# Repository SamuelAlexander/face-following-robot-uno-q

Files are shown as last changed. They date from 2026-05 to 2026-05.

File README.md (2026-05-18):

# Face-following robot with Arduino UNO Q and Edge Impulse

Build a desk-sized robot that detects a human face using on-device ML and steers toward it in real time,  all running on the [Arduino UNO Q](https://store.arduino.cc/products/uno-q).

**Created by:** Samuel Alexander  
**Edge Impulse public project:** https://studio.edgeimpulse.com/public/953867/live  
**GitHub repository:** https://github.com/SamuelAlexander/face-following-robot-uno-q  
**Demonstration video:** https://youtu.be/TYtrBvlE7Mc

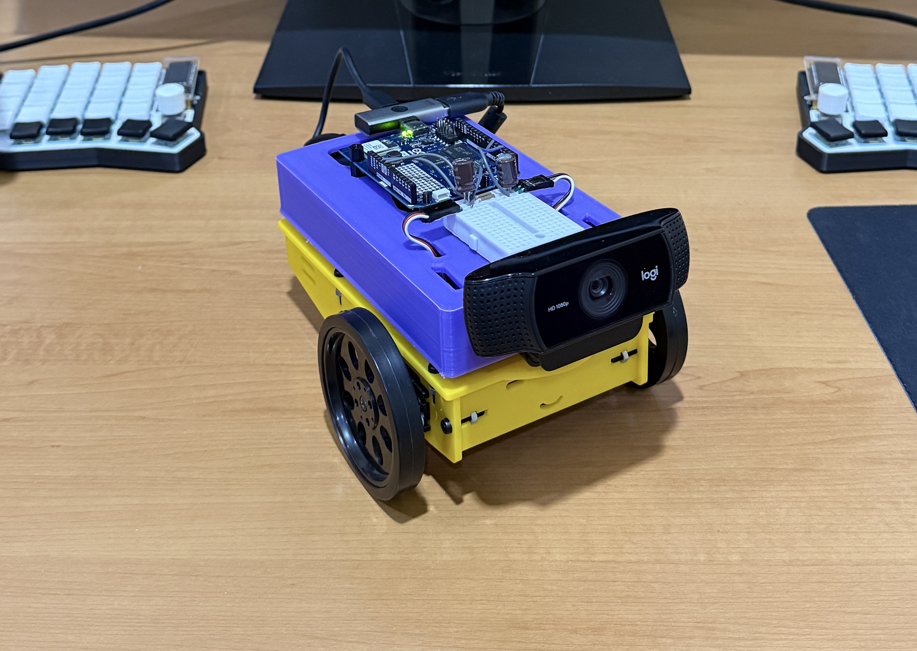
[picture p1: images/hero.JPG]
hero


## Introduction

This project combines computer vision and robotics on a single board. A camera captures video, a lightweight face-detection model (powered by Edge Impulse) locates the face, and a proportional controller converts that position into differential wheel commands, all at ~10-15 FPS.

The UNO Q's **split architecture** makes this possible:

- **MPU** (Qualcomm, Linux) --> runs the ML model and control logic in Python
- **MCU** (STM32, Zephyr RTOS) --> drives servo PWM with real-time precision

The two processors communicate over **Bridge RPC**, a MessagePack-based protocol over an internal serial link. This separation keeps heavy inference off the real-time path and motor control deterministic.

A browser-based **Web UI** lets you monitor detections and tune steering parameters live, no recompilation needed.

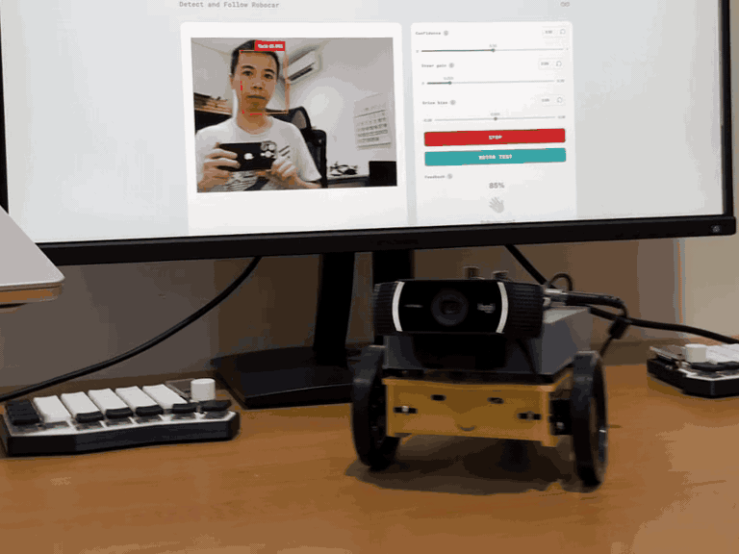
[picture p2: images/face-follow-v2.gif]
face-follow


### What you'll learn

- How the UNO Q's MPU/MCU split architecture works
- Using App Lab **bricks** (pre-built middleware) for AI and web interfaces
- Bridge RPC communication between Python and an Arduino sketch
- Proportional steering control for differential-drive robots
- Live parameter tuning through a Socket.IO web dashboard

## Prerequisites

### Hardware

| Component | Used in This Project | Notes |
|---|---|---|
| Arduino UNO Q | — | 2 GB or 4 GB variant |
| USB webcam | Logitech C922 Pro Stream | Most UVC-compatible webcams work |
| 2x continuous-rotation servo | Parallax Continuous Rotation Servo | Any continuous servo with 1000-2000 us pulse range |
| USB-C power bank (PD) | 20000 mAh, USB-C PD output | Must supply stable 5 V / 2+ A |
| USB-C splitter | With USB-A port | Powers UNO Q via USB-C, camera via USB-A |
| Small decoupling capacitors | 100 uF electrolytic across servo power/GND | Reduces servo electrical noise |
| Robot chassis | Custom 3D-printed (STL files included) | Any two-wheel platform works |
| Jumper wires | — | Signal + power for servos |

### Software

- **Arduino App Lab v0.6** or later (runs in-browser, no local install needed)
- A computer on the same network as the UNO Q
- Edge Impulse Studio account

### Source code

The full project source is available at: https://github.com/SamuelAlexander/face-following-robot-uno-q  

## Architecture overview

The system has three layers:

```
┌──────────────┐    Socket.IO   ┌────────────────────────────────┐
│   Browser    │◄──────────────►│  MPU (Linux / Python)          │
│   Web UI     │                │  - VideoObjectDetection brick  │
│   Tuning +   │                │  - Steering controller         │
│   Monitoring │                │  - WebUI brick                 │
└──────────────┘                └──────────┬─────────────────────┘
                                           │ Bridge RPC (MsgPack)
                                ┌──────────▼─────────────────────┐
                                │  MCU (STM32 / Zephyr RTOS)     │
                                │  - Receives pulse commands     │
                                │  - Drives PWM on D3 + D6       │
                                └──────────┬─────────────────────┘
                                           │ PWM (50 Hz, 1000-2000 us)
                                ┌──────────▼─────────────────────┐
                                │  Left servo    Right servo     │
                                └────────────────────────────────┘
```

**Why split MPU and MCU?** ML inference is computationally heavy and non-deterministic, it belongs on a Linux processor. Servo PWM timing is safety-critical and must be jitter-free, it belongs on a real-time microcontroller. Bridge RPC connects the two with ~8 ms round-trip latency.

## Hardware assembly

### Chassis overview

The robot uses a simple **differential-drive** layout:

- Two continuous-rotation servos mounted on opposite sides
- A rear caster or skid point for stability
- A top-mounted platform for the UNO Q and camera
- The USB power bank sits on or below the platform as ballast

Continuous-rotation servos simplify wiring. A 1500 us pulse means stop, below 1500 spins one way, above 1500 spins the other.

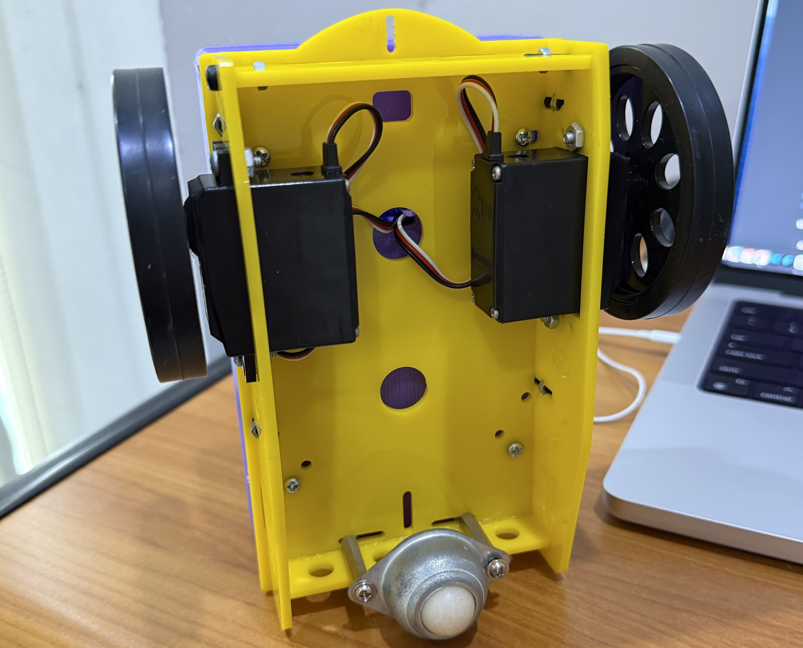
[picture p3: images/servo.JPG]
servo


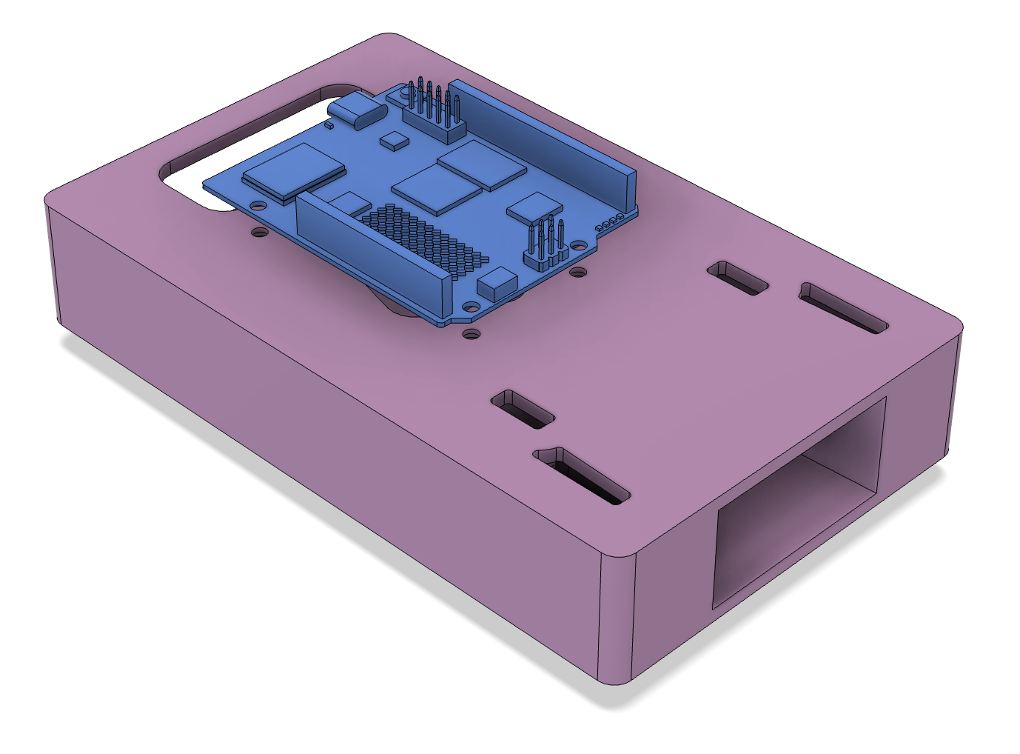
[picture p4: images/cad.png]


### Wiring

| Servo | Signal Pin | Power | Ground |
|---|---|---|---|
| Left wheel | D3 | 5 V | GND |
| Right wheel | D6 | 5 V | GND |

Place a **100 uF capacitor** across the servo power and ground rails to absorb current spikes.

Connect the webcam to the USB-A port on the USB-C splitter. The USB-C side powers the UNO Q.

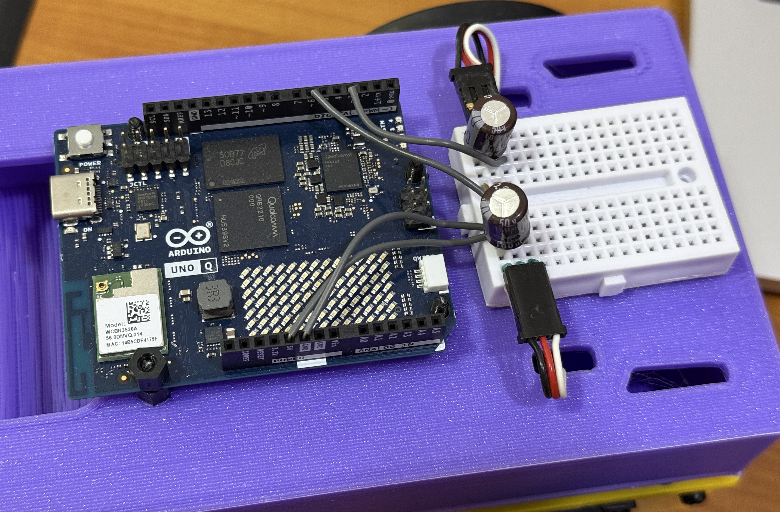
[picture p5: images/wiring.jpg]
wiring


> **Note:** The right servo is mounted mirrored relative to the left. The firmware handles this with a pulse inversion flag, no crossed wires needed.

## Project setup in App Lab

### File structure

Every App Lab project follows this layout:

```
detect-and-follow-robocar/
├── app.yaml              # App manifest: bricks and model selection
├── python/
│   └── main.py           # MPU application (detection + control)
├── sketch/
│   ├── sketch.ino        # MCU firmware (servo PWM)
│   └── sketch.yaml       # Build config (board, libraries)
└── assets/
    ├── index.html         # Web UI page
    ├── app.js             # Web UI logic (Socket.IO client)
    └── style.css          # Styling
```

### Configuring bricks

**Bricks** are pre-built middleware packages that run on the MPU. They provide high-level capabilities without writing boilerplate. This project uses two:

In `app.yaml`:

```yaml
name: Detect and follow robocar
description: Robot car that follows a target object.
bricks:
- arduino:video_object_detection:
    model: face-detection
- arduino:web_ui: {}
icon: 🚙
```

- **`video_object_detection`**, captures camera frames, runs the face-detection model, and delivers results to your Python code via callbacks
- **`web_ui`**, serves the HTML/JS dashboard and provides a Socket.IO server for real-time communication

The `model: face-detection` line selects a built-in lightweight face-detection model. No training or Edge Impulse account needed.

### Sketch dependencies

In `sketch/sketch.yaml`, the key libraries are **Arduino_RouterBridge** (Bridge RPC) and **Servo** (PWM output):

```yaml
profiles:
  default:
    fqbn: arduino:zephyr:unoq
    platforms:
      - platform: arduino:zephyr
    libraries:
      - Arduino_RouterBridge (0.4.1)
      - Servo
      - MsgPack (0.4.2)
```

## The MCU sketch: Servo control

The MCU firmware is intentionally minimal, it receives pulse-width commands over Bridge RPC and writes them to the PWM hardware. All decision-making lives on the MPU.

### Bridge RPC endpoint

The sketch exposes a single function that the MPU can call. It uses the Arduino **Servo** library for reliable pin-level PWM output:

```cpp
#include <Arduino_RouterBridge.h>
#include <Servo.h>

Servo leftServo;
Servo rightServo;

bool set_wheel_pwm(int left_us, int right_us) {
  uint32_t left  = clamp_pulse_us(left_us);   // Clamp to 1000-2000
  uint32_t right = clamp_pulse_us(right_us);

  left  = apply_invert(left,  kInvertLeftWheel);   // false
  right = apply_invert(right, kInvertRightWheel);   // true — right is mirrored

  leftServo.writeMicroseconds(left);    // D3
  rightServo.writeMicroseconds(right);  // D6
  return true;
}

void setup() {
  Bridge.begin();
  leftServo.attach(3);
  rightServo.attach(6);
  leftServo.writeMicroseconds(1500);   // Start stopped
  rightServo.writeMicroseconds(1500);
  Bridge.provide_safe("set_wheel_pwm", set_wheel_pwm);
}

void loop() {}   // All control is event-driven via RPC
```

**Key concepts:**

- **Arduino Servo library** handles PWM output via `attach(pin)` and `writeMicroseconds()`. This is more portable than the low-level Zephyr PWM API (`pwm_set_dt`), which depends on devicetree index mappings that can vary between board revisions.
- **`Bridge.provide_safe()`** registers the function so it runs in the Arduino `loop()` context, safe for hardware operations like PWM writes. Never use `Bridge.provide()` for GPIO/servo/motor calls, as that runs in a background RPC thread where hardware APIs can fail.
- **Pulse inversion** handles the mirrored right servo: `inverted = 3000 - pulse`. This mirrors the pulse around the 1500 us stop point, so the same "forward" command from Python moves both wheels in the same physical direction.
- **Empty `loop()`** is correct, the Bridge library hooks into the loop internally to dispatch queued `provide_safe` callbacks.

### Continuous-rotation servo basics

| Pulse (us) | Behavior |
|---|---|
| 1500 | Stop |
| 1000 | Full speed, one direction |
| 2000 | Full speed, opposite direction |

The closer to 1500, the slower the wheel turns. This project uses offsets up to ±125 us for responsive but desk-safe motion.

## The MPU application: Detection to steering

The Python application on the MPU handles three responsibilities: receiving detections from the vision brick, computing steering commands, and communicating with both the MCU and the web UI.

### Brick initialization

```python
from arduino.app_utils import App, Bridge
from arduino.app_bricks.web_ui import WebUI
from arduino.app_bricks.video_objectdetection import VideoObjectDetection

ui = WebUI()
detection_stream = VideoObjectDetection(confidence=0.5, debounce_sec=0.0)
```

The `VideoObjectDetection` brick fires a callback every time it processes a frame. The `on_detect_all` variant fires for every frame, including ones with no detections, useful for keeping a watchdog timestamp fresh:

```python
detection_stream.on_detect_all(on_detections)
App.run()
```

### Detection format

The brick delivers detections as a dictionary, with each label mapped to a **list** of detection instances:

```python
{
    "face": [
        {"confidence": 0.89, "bounding_box_xyxy": (144, 83, 234, 209)},
        # ...more faces if multiple detected
    ]
}
```

Each instance contains a `confidence` score and a `bounding_box_xyxy` tuple of `(x_min, y_min, x_max, y_max)` in pixel coordinates. The `TARGET_CLASS` constant must match the model's label exactly, "face"` for the built-in face-detection model.

> **Important:** The per-label value is always a list, even for a single detection. Code that expects a plain dict per label (without the list wrapper) will silently miss all detections.

### Proportional steering controller

The controller converts the face's horizontal position into differential wheel commands:

```
1. Find the face's bounding box center
2. Normalize to 0.0 (left edge) — 1.0 (right edge)
3. Compute heading error: (center - 0.5) x 2.0  →  range -1.0 to +1.0
4. Apply deadband (ignore small errors to suppress jitter)
5. Shape response with a power curve (compress large errors)
6. Scale by STEER_GAIN → turn speed
7. Convert to differential pulses: left = 1500 + turn, right = 1500 - turn
```

```python
heading_error = (target_cx - 0.5) * 2.0
if abs(heading_error) < CENTER_DEADBAND:
    heading_error = 0.0

shaped = math.copysign(abs(heading_error) ** STEER_CURVE, heading_error)
turn = clamp(STEER_SIGN * STEER_GAIN * shaped, -MAX_TURN_SPEED, MAX_TURN_SPEED)

left_us  = speed_to_pulse(turn)    # 1500 + turn x 500
right_us = speed_to_pulse(-turn)   # 1500 - turn x 500
```

The **power curve** (`STEER_CURVE = 0.4`) makes the response more aggressive for small errors and softer near the frame edges, a simple alternative to PID that works well for this use case.

### Coasting and lost target

When the face momentarily disappears (occlusion, blink, brief look-away), the controller **coasts** on the last-known position for `TRACKING_TIMEOUT` seconds (default 0.5s) before declaring the target lost. This avoids jittery stop-start behavior.

When the target is truly lost, the robot stops. An optional search mode (disabled by default) slowly rotates to scan for the face.

### Bridge communication and rate limiting

The UNO Q Bridge has no internal queue, sending commands too fast crashes the serial link. The application rate-limits Bridge calls to a maximum of 20 Hz (50 ms intervals):

```python
MIN_BRIDGE_INTERVAL = 0.05  # seconds

if now - _last_bridge_ts < MIN_BRIDGE_INTERVAL:
    return   # Skip this update

Bridge.notify("set_wheel_pwm", left_us, right_us)
```

`Bridge.notify()` is fire-and-forget (no response waited), which avoids blocking the inference loop. `Bridge.call()` would wait for a return value and slow down the control loop.

> **Safety note:** The emergency stop bypasses rate limiting entirely to guarantee the MCU receives the stop command immediately.

### Watchdog

A background thread checks whether detection callbacks have stopped arriving. If no callback fires for 1.5 seconds (indicating a camera or pipeline failure), the watchdog forces a stop command:

```python
def _watchdog_loop():
    while True:
        time.sleep(0.25)
        if time.monotonic() - _last_detection_ts > NO_DETECTION_TIMEOUT:
            send_lost_target_command()
```

## The web UI

The dashboard runs in any browser on the same network and provides live monitoring and parameter tuning.

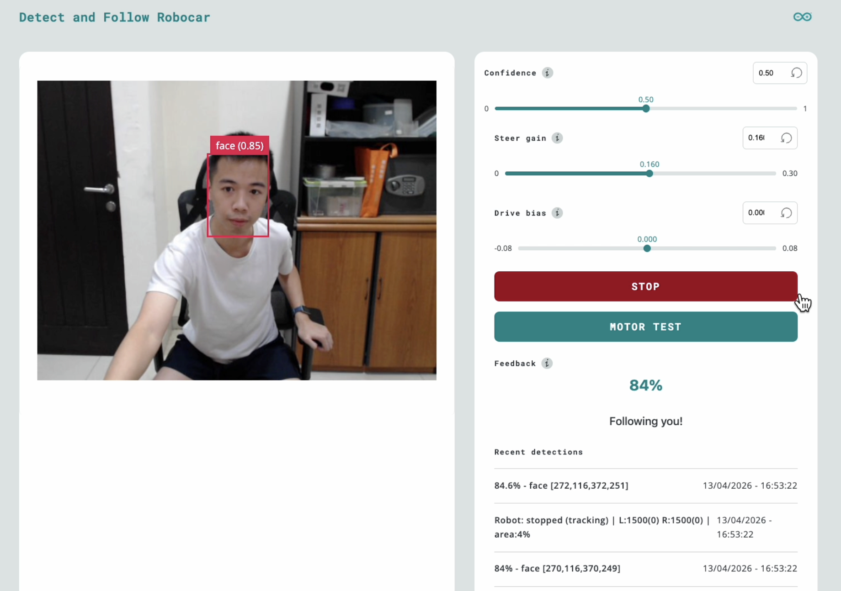
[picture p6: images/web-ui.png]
web-ui


### Features

| Element | Function |
|---|---|
| **Video stream** | Live camera feed via iframe (port 4912) |
| **Confidence slider** | Adjusts minimum detection confidence (0.0-1.0) |
| **Steer gain slider** | Controls how aggressively the robot turns (0-0.30) |
| **Drive bias slider** | Adds fixed forward/backward offset (-0.08 to +0.08) |
| **Emergency stop** | Immediately halts all wheel motion |
| **Motor test** | Runs a left-right-stop sequence to verify servo wiring |
| **Feedback** | Visual confirmation when a face is detected |
| **Recent detections** | Live log of the last 5 detection and state events |

All slider changes take effect immediately via Socket.IO, no restart required. This makes tuning fast: adjust a slider, observe the robot's response, repeat.

## Deploy and run

### App Lab GUI

1. Open **Arduino App Lab** in your browser
2. Create a new app or import the project files
3. Click **Run**, App Lab compiles the sketch, flashes the MCU, and starts the Python app

### First boot checklist

1. **Check the log** for the `sample_detections` line, it prints the raw detection payload on the first frame. Verify:
   - The label is `"face"` (matches `TARGET_CLASS`)
   - The bounding box coordinates are reasonable for your camera resolution
2. **Open the Web UI** at `http://<UNO_Q_IP>:7000`, you should see the video stream and detection events appearing in "Recent detections"
3. **Verify servos**, press the **Motor Test** button in the UI. Both wheels should turn left, pause, then turn right. If not, check wiring and servo power before proceeding to face tracking.

face-follow

## Tuning guide

### Steering direction

If the robot turns *away* from your face instead of toward it, flip the steering sign in `main.py`:

```python
STEER_SIGN = -1.0   # Flip if left/right tracking is mirrored
```

### Frame width calibration

Check the `sample_detections` log output. If the max `x` coordinate in `bounding_box_xyxy` is significantly different from `FRAME_WIDTH_FALLBACK` (default 640), update the constant to match. A wrong value causes asymmetric or weak steering.

### Gain tuning

Start with these defaults and use the Web UI sliders to adjust:

| Parameter | Default | Effect |
|---|---|---|
| `STEER_GAIN` | 0.15 | Higher = faster turns, risk of overshoot |
| `MAX_TURN_SPEED` | 0.25 | Hard cap on wheel speed (~±125 us). Must exceed servo dead zone. |
| `CENTER_DEADBAND` | 0.05 | Larger = more tolerance before turning |
| `DRIVE_BIAS` | 0.0 | Positive = creep forward, negative = backward |

**Workflow:** Start with the robot on a desk. Increase `STEER_GAIN` until the robot centers on your face smoothly. If it oscillates (overshoots left-right), reduce the gain. Once tuned, update the defaults in `main.py` so the robot starts with good values.

## Troubleshooting

| Symptom | Likely Cause | Fix |
|---|---|---|
| UI shows detections but "lost target - stopped" | `TARGET_CLASS` doesn't match model label | Check `sample_detections` log, set `TARGET_CLASS` to the exact label string |
| Wheels don't move at all | Servo power, wiring, or Bridge issue | Use the **Motor Test** button to isolate; check servo power rail and signal wires on D3/D6 |
| Robot turns the wrong way | Steering sign or inversion mismatch | Flip `STEER_SIGN` to `-1.0`; or swap `LEFT/RIGHT_WHEEL_INVERTED` flags |
| Jerky, oscillating motion | Gain too high or deadband too low | Reduce `STEER_GAIN` via slider; increase `CENTER_DEADBAND` |
| Video stream not loading | Camera not detected | Check USB connection; try a powered USB hub |
| Emergency stop doesn't work | Socket.IO disconnected | Check for error banner in the Web UI |

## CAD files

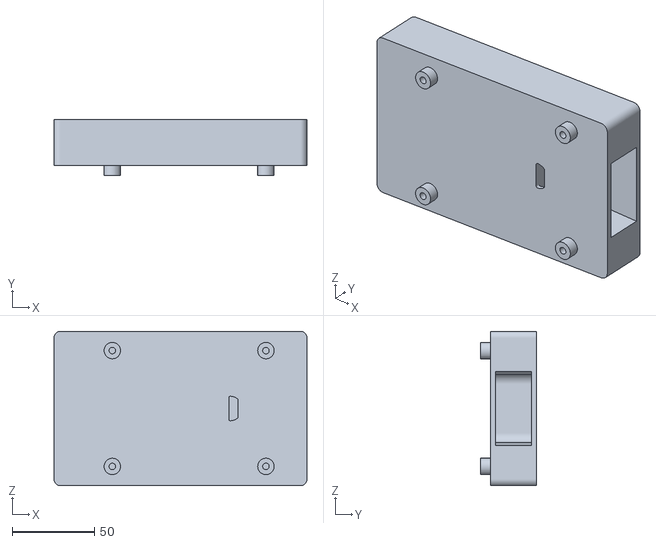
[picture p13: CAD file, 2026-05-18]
stl/UNO-car-frame.stl
154.0 x 34.0 x 94.0

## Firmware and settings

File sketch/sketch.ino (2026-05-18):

// SPDX-FileCopyrightText: Copyright (C) ARDUINO SRL (http://www.arduino.cc)
//
// SPDX-License-Identifier: MPL-2.0

// -----------------------------------------------------------------------
// MCU Sketch: Continuous-rotation servo control via Bridge RPC
//
// Two servos are driven via the Arduino Servo library on the UNO Q's
// STM32 MCU.  The MPU (Python) calls "set_wheel_pwm" over the Bridge
// and sends direct wheel pulse commands (microseconds).
// -----------------------------------------------------------------------

#include <Arduino_RouterBridge.h>
#include <Servo.h>

namespace {

// --- Pin assignments (change here if you re-wire) --------------------
const int kLeftServoPin  = 3;   // D3
const int kRightServoPin = 6;   // D6

// Standard continuous-rotation servo pulse range in microseconds.
const uint32_t kStopPulseUs = 1500;
const uint32_t kMinPulseUs  = 1000;
const uint32_t kMaxPulseUs  = 2000;

// Flip this if left wheel runs backward when commanded forward.
const bool kInvertLeftWheel  = false;
// Flip this if right wheel runs backward when commanded forward.
const bool kInvertRightWheel = true;

Servo leftServo;
Servo rightServo;

uint32_t clamp_pulse_us(int pulse_us) {
  if (pulse_us < static_cast<int>(kMinPulseUs)) return kMinPulseUs;
  if (pulse_us > static_cast<int>(kMaxPulseUs)) return kMaxPulseUs;
  return static_cast<uint32_t>(pulse_us);
}

uint32_t apply_invert(uint32_t pulse_us, bool invert) {
  if (!invert) return pulse_us;
  return (kStopPulseUs * 2U) - pulse_us;
}

}  // namespace

// --- Bridge RPC handler ----------------------------------------------
// Called from Python: Bridge.call("set_wheel_pwm", left_us, right_us)
bool set_wheel_pwm(int left_us, int right_us) {
  uint32_t left  = clamp_pulse_us(left_us);
  uint32_t right = clamp_pulse_us(right_us);

  left  = apply_invert(left,  kInvertLeftWheel);
  right = apply_invert(right, kInvertRightWheel);

  leftServo.writeMicroseconds(left);
  rightServo.writeMicroseconds(right);
  return true;
}

void setup() {
  Bridge.begin();

  leftServo.attach(kLeftServoPin);
  rightServo.attach(kRightServoPin);

  // Start both servos in the stopped position.
  leftServo.writeMicroseconds(kStopPulseUs);
  rightServo.writeMicroseconds(kStopPulseUs);

  // Expose the RPC so the MPU can control the servos.
  Bridge.provide_safe("set_wheel_pwm", set_wheel_pwm);
}

void loop() {
  // Nothing to do — servo state is updated via Bridge RPC callbacks.
}
